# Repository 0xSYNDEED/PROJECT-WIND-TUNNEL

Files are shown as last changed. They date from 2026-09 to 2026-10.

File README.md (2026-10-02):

# Miniature Open-Circuit Subsonic Wind Tunnel

ME 366 (Electromechanical System Design) project, Group A13, Department of Mechanical Engineering, BUET, 2026.

A low-cost wind tunnel with a 160 × 160 × 340 mm test section (16–18 m/s, Re ≈ 1.2 × 10⁵), a dual-lever load-cell balance, surface-pressure taps and a Pitot probe. It was validated against Ansys Fluent simulations of its own test section, with and without the model's support stand. Test models: NACA 4418 airfoil (−5° to +10°) and a 25° Ahmed body.

**Read the report first:** [`[Docs] Wind Tunnel/Wind Tunnel Report - Group A13.pdf`](<[Docs] Wind Tunnel/Wind Tunnel Report - Group A13.pdf>). The poster is in the same folder.

**Authors:** Ahnaf Masud Syndeed, Hasibul Karim Ratul, Mubasshira, Bivashindhu Datta Badhon

## What's where

| Folder | Contents |
|---|---|
| `[Docs] Wind Tunnel/` | Final report (PDF) and poster |
| `[CAD] Wind Tunnel/` | SolidWorks parts and assemblies of the tunnel, balance, models, Pitot stand and smoke rake; DXF files for laser cutting. Parts marked *(Obsolete)* were not used in the final tests |
| `[CFD] Wind Tunnel/` | For every case, with and without the stand: Ansys Discovery geometry prepared for meshing, with named selections (`.dsco`); Fluent project files (`.flprj`); monitor histories (`.out`); simulated geometry (`.STEP`); and Cp exports |
| `[Codes] Wind Tunnel/` | Arduino sketches and MATLAB scripts (below) |

**Arduino** (Mega 2560):

- `LiftDrag_V2` reads the force balance and the Pitot probe.
- `PressureReadings` was used for all reported pressure data.
- `PressureSurvey` is a later, unused rewrite, kept for future surveys.
- `LiftDrag_V1` is the superseded first version of the force sketch.

**MATLAB** (`# MATLAB Scripts/`): all measured data are in `Wind_Tunnel_Experimental_Coefficients.xlsx`. The `[NACA]` and `[Ahmed]` folders hold the scripts that produce the report's comparison plots. `Misc/` holds the averaging script for the oscillating CFD case. Keep the folder structure as it is, because the scripts find their inputs by relative path.

## Software

- **SolidWorks 2026** for the CAD. Use the STEP/DXF files with older versions.
- **Ansys Student 2026 R1**: Discovery for geometry preparation (`.dsco`), and Fluent in Meshing mode (mesh) and Solution mode (solver).
- **MATLAB R2020b or newer.** MATLAB Online works, and no toolboxes are needed.
- **Arduino IDE 2.x** with the `HX711` library by bogde.

## Not included

- **Fluent mesh files** (`.msh.h5`, about 100 MB each), which hold both the mesh and the meshing workflow and open in Fluent's Meshing mode. Most of them exceed GitHub's 100 MB file limit.
- **Fluent case and data files** (`.cas.h5`, `.dat.h5`). With the mesh files, they total about 12 GB.
- **Report source:** only the report PDF is included.
- **3D-print files (STL/3MF):** export them from the SolidWorks parts.
- **Temporary and log files.**

To regenerate the mesh, case and data files, import the `.dsco` geometry in Fluent's Meshing mode and use the settings in the report (Table 2.3).

## License

Code (Arduino firmware and MATLAB scripts) is released under the MIT License (see `LICENSE`). CAD files, data, figures and documents are released under [CC BY 4.0](https://creativecommons.org/licenses/by/4.0/).

## Citation

A. M. Syndeed, H. K. Ratul, Mubasshira, B. D. Badhon, *Design, Instrumentation and CFD Validation of a Miniature Open-Circuit Subsonic Wind Tunnel for Low-Reynolds-Number Aerodynamics*, ME 366 Project Report, BUET, 2026.

Supervised by Dr. Kazi Arafat Rahman, Md Moyeenul Hossain Ratul, Rafiul Haq and Dilshad Jahan Ritu.

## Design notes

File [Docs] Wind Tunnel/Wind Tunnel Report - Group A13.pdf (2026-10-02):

Bangladesh University of

Engineering and Technology

Department of Mechanical Engineering

ME 366 · Electromechanical System Design

Project Report

Design, Instrumentation and CFD Validation

of a Miniature Open⁻Circuit Subsonic Wind Tunnel

for Low⁻Reynolds⁻Number Aerodynamics

Group A13

Submitted by

Ahnaf Masud Syndeed
Student ID 2210047
Hasibul Karim Ratul
Student ID 2210032
Mubasshira
Student ID 2210031
Bivashindhu Datta Badhon
Student ID 2210027

Submitted to

Dr. Kazi Arafat Rahman
Associate Professor
Md Moyeenul Hossain Ratul
Lecturer
Rafiul Haq
Lecturer
Dilshad Jahan Ritu
Lecturer

Date of submission: October 2, 2026

Miniature Subsonic Wind Tunnel: Design & CFD Validation | Group A13 | ME 366

Abstract

Low-cost wind tunnels can give student teams access to low-Reynolds-number aerodynamic testing, but their measurements are only useful once their accuracy is known. This work describes the design, construction and validation of a miniature open-circuit, induced-draft subsonic wind tunnel with a straw honeycomb, a 6.25:1 fifth-order polynomial contraction and a 160 × 160 × 340 mm test section running at 16–18 m/s (Re ≈ 1.2 × 10⁵
). The tunnel is instrumented with a dual-lever load-cell balance for lift and drag, surface-pressure taps read by a differential pressure sensor, a Pitot-static probe and a glycerin-smoke rake, all logged through an Arduino microcontroller. A NACA 4418 airfoil (−5

◦

to 10◦
) and a modified
Ahmed body were tested and compared with steady k–ω SST simulations in Ansys Fluent of the confined test section both with and without the model support stand. The tunnel reproduces the computed trends: the zero-lift angle agrees to within 0.1

◦
(−3.7
- measured), the measured drag lies within 12% of the with-stand simulations, the Ahmed-body drag coefficient is within 9%, and the pressure distributions match the computed shapes. Without the stand in the simulations, the drag differences grow to 22–80%, showing that the support stand adds significant drag that must be modeled in CFD for small-tunnel validation. The measured lift is 15–20% low at 5

◦

and 10◦
, and the measured suction is weaker than predicted; these differences are attributed to low-Reynolds-number boundary-layer effects, balance pivot coupling and calibration, and pressure-line leakage, and improvements are proposed for each.

Keywords: subsonic wind tunnel; low Reynolds number; CFD validation; force balance; surface pressure; NACA 4418; Ahmed body

Contents

Abstract | 1
1 | Introduction | 5
2 | Methodology | 8
3 | Results | 18
4 | Discussion | 23
5 | Conclusion and Future Work | 28
Data and Code Availability | 29
Acknowledgments | 29
A Fabrication and Assembly Sequence | 31
B | Key Code Excerpts | 31
C NACA 4418 Surface Pressure Data | 33

List of Figures

1.1 CAD model of the wind tunnel with the NACA 4418 and the force balance installed,
viewed from the inlet | | 6
2.1 The tunnel as built. Air is drawn from left to right by the fan at the downstream end. . . . | 9
2.2 Side view of the tunnel with principal dimensions (mm), showing the straw honeycomb,
the three screens, the Pitot-static probe and the model position. The flexible coupling and
fan downstream of the diffuser are not shown | 9
2.3 Tunnel details. (a) The settling-chamber inlet with the drinking-straw honeycomb. (b)
CAD side view of the test section with the NACA 4418 on its stand, the stand’s linkage
to the balance below the floor, and the Pitot mount near the inlet (left). (c) CAD view
of the Pitot mount on the test-section floor; the holes in the far wall are the ports for the
pressure-tap tubes | 9
2.4 Test models (CAD renders) and their pressure-tap positions. In (c) the dashed line is the
camber line | 10
2.5 The dual-lever force balance. (a) Drag turns the stand about its lower pivot and is passed, amplified 4.5:1, through the upper link to the drag load cell; lift turns the lower lever about
its pivot and presses, amplified 4:1, on the lift load cell. (b, c) The balance outside the tunnel, with the HX711 amplifiers and the Arduino Mega on the base plate. The servo on
the stand belonged to the original angle-of-attack drive and was not used in the final tests. 12 2.6 Data-acquisition wiring. Both HX711 amplifiers use two digital pins each (data and clock); the pressure sensor feeds analog input A3. The sensor’s reference port stays on
the Pitot static port, and its positive port is switched between the Pitot total port and the
surface taps | 13
2.7 Volume mesh for the NACA 4418 at 0
- with the stand: polyhedral cells with boundary
(prism) layers on the model, the stand and the tunnel walls | 15
2.8 Example of a steady solution that settled into a limit cycle instead of converging (NACA 4418, 10◦
, without stand; period about 98 iterations). The shaded band is the averaging
window of four whole cycles and the dashed lines are the resulting means | 16
3.1 NACA 4418 force coefficients vs. angle of attack: wind tunnel (error bars: estimated
uncertainty) and CFD with and without the model stand | 19
3.2 NACA 4418 lift-to-drag ratio vs. angle of attack | 19
3.3 NACA 4418 surface pressure coefficient at α = −5

◦
, 0

◦
, 5

◦

and 10◦
: wind-tunnel taps
(error bars: estimated uncertainty) vs. the with-stand CFD distribution on the tap plane. . 21 3.4 NACA 4418 tap pressures grouped by surface: wind tunnel (solid) vs. with-stand CFD at
the taps (dashed) for each angle of attack | 21
3.5 Ahmed body upper-surface pressure coefficient along its length: wind tunnel vs. with-stand
CFD (continuous curve and tap means ±1σ of the averaged solution) | 22
3.6 Glycerin smoke-rake visualization of the NACA 4418 (flow from left to right). Images converted to grayscale, sharpened for contrast and cropped to a common frame; no other
processing | 22

List of Tables

1.1 Attributes of a complex engineering problem and how this project meets them | 7
2.1 Test matrix | 13
2.2 Uncertainty inputs | 14
2.3 CFD solver and mesh settings | 15
2.4 Hardware and software components | 16
3.1 Nominal test conditions (ρ = 1.225 kg/m³
) | 18
3.2 NACA 4418 force coefficients: wind tunnel (WT) vs. CFD with and without the model
stand. Δ = (WT − CFD)/|CFD| | 18

3.3 NACA 4418 tap pressure difference C

WT
p − C

CFD
| p

(CFD with stand); WT uncertainty in parentheses. Positive values mean the WT Cp is higher (less suction) than the CFD. Entries within the WT uncertainty are marked ∗
| 20
3.4 Ahmed body drag coefficient. WT ±: estimated uncertainty; CFD ±: 1 SD of the averaged
monitor; Δ = (WT − CFD)/|CFD| | 20
4.1 Drag added by the stand. CFD increment = C

with stand
d

− C

without stand
d

, also given as a
force at the test dynamic pressure and as a share of the with-stand Cd. WT excess

= C

WT
d

− C

without stand
d
| 23
4.2 Challenges faced and how they were resolved | 26
C.1 NACA 4418 tap pressure coefficients: wind tunnel vs. CFD (with stand) | 33

### 1 Introduction

### 1.1 Background and Motivation

Aerodynamic data at Reynolds numbers in the range 10⁴–10⁵ underpin the design of small unmanned aircraft, scale models of ground vehicles and many introductory aerodynamic experiments [1]. In this range the boundary layer stays laminar over much of the surface, and laminar separation, transition and reattachment make the forces sensitive to small changes in Reynolds number, surface finish and freestream turbulence [2]. Such flows are hard to predict, so computations need experimental checks. Wind tunnels that can provide these checks are rarely available to undergraduate teams: commercial teaching tunnels are expensive, and even a recently published open, low-cost design costs several thousand US dollars in hardware [3].
A small tunnel built from commonly available materials can fill this gap, but its measurements are useful only once their accuracy is known, and validating a small facility is difficult. The model blocks a significant fraction of the test section, the support stand is comparable in size to the model and adds drag and interference of its own, and the loads are of the order of one newton or less, close to the resolution of low-cost sensors. This project addresses both needs. It designs, builds and instruments a miniature open-circuit wind tunnel, and then assesses the tunnel’s measurement capability against a computational model of the same confined test section, stand included.

### 1.2 Related Work

Design guidance for small low-speed tunnels is well established. Mehta and Bradshaw [4] give rules for the settling chamber, honeycomb (cell length of six to eight diameters), screens, contraction ratio and diffuser, and Barlow et al. [5] treat tunnel design, instrumentation and wall corrections in detail. For the contraction, Bell and Mehta [6] showed that a fifth-order polynomial wall, with zero slope and curvature at both ends, balances exit-flow uniformity against the risk of boundary-layer separation near the inlet and exit; the profile is widely used in small tunnels and is adopted here. Ismail et al. [3] published an open design for a low-cost, open-loop suction tunnel for aerodynamic testing at up to 15 m/s, with step-by-step build files. The present tunnel uses the same suction layout at a smaller scale, built largely from laser-cut plywood, 3D-printed parts and hobby-grade electronics, and adds a force balance and surface-pressure measurement.
Two standard test models were chosen because their behavior is well documented. The NACA four-digit sections are among the most thoroughly catalogued airfoils [7]; the cambered NACA 4418 produces lift at zero incidence, with a zero-lift angle near −4

◦
, which gives a direct check on the lift measurement. The Ahmed body [8] is the standard simplified road vehicle for bluff-body studies; its wake, and hence its drag, is governed by the rear slant angle, the flow over the slant remaining largely attached below a critical angle of about 30◦
For the computations, steady Reynolds-averaged Navier–Stokes (RANS) simulation with the k–ω SST model [9, 10] is the usual engineering choice. The model treats the boundary layer as fully turbulent from the leading edge, however, so it cannot reproduce the laminar separation and transition that dominate at low Reynolds numbers [2]. This limitation matters for the lift comparison in Section 4.3.

### 1.3 Objectives

The objectives of the project were to:
1. design and build a modular, low-cost, open-circuit subsonic wind tunnel with a 160 mm × 160 mm test section running at 16–18 m/s, giving Re ≈ 1.2 × 10⁵ on a 100 mm chord;
2. instrument the tunnel to measure lift, drag, model surface pressures and freestream speed with a low-cost microcontroller data-acquisition system;
3. build a CFD digital twin of the confined test section, with the support stand included, and use it to assess the tunnel’s force and pressure measurements on a NACA 4418 airfoil (−5

◦

to 10◦
) and a
modified Ahmed body;

4. identify and, where possible, quantify the sources of disagreement, as a basis for improving the facility; and
5. demonstrate qualitative smoke flow visualization.

### 1.4 Facility Overview and Key Features

The tunnel (Fig. 1.1) is an open-circuit, induced-draft facility about 1.6 m long, excluding the fan. Room air enters through a straw honeycomb in a 400 mm × 400 mm settling chamber, is accelerated through a 6.25:1 contraction into the 160 mm × 160 mm, 340 mm long test section, and is slowed in a diffuser before being drawn out by a 350 W axial drum fan. Its main features are:
- Modular, low⁻cost construction: flanged plywood and 3D-printed sections screwed together, so the

tunnel can be taken apart for transport and any section replaced, for a total cost of about BDT 50,000 (under US$500) including scrapped parts (Section 2.8);
- Flow conditioning: drinking-straw honeycomb (L/D ≈ 7), three screens and a fifth-order

polynomial contraction;
- Three measurement modes: a dual-lever load-cell balance for lift and drag, surface-pressure taps

read by a differential pressure sensor, and a Pitot-static probe for the freestream speed;
- Interchangeable models: 3D-printed NACA 4418 and Ahmed-body models with built-in pressure

taps, mounted on a stand linked to the balance;
- Optical access and flow visualization: an acrylic side window and a removable glycerin-smoke

rake;
- Open tools: Arduino firmware and MATLAB scripts, with code and CAD shared in a public

repository (see Data and Code Availability); and
- CFD digital twin: an Ansys Fluent model of the confined test section, model and stand, used to

validate the measurements.
The design, instrumentation and procedures are described in Section 2, the results in Section 3 and their interpretation in Section 4.

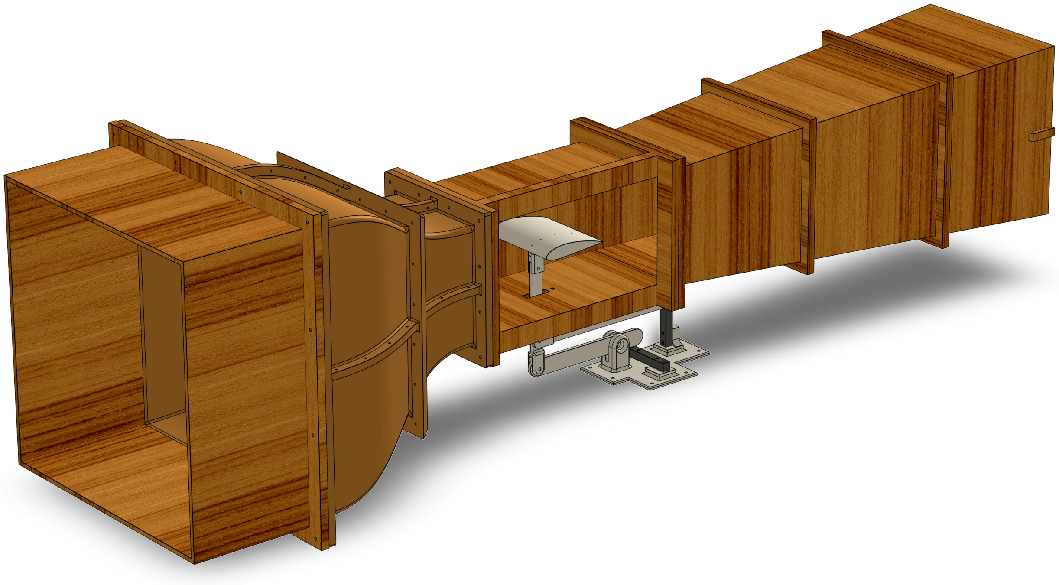
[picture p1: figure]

Figure 1.1: CAD model of the wind tunnel with the NACA 4418 and the force balance installed, viewed from the inlet.

### 1.5 The Project as a Complex Engineering Problem

Under the graduate-attribute framework of the International Engineering Alliance [11], adopted by the Board of Accreditation for Engineering and Technical Education (BAETE), a complex engineering problem (CEP) is one that cannot be resolved without in-depth engineering knowledge (attribute P1) and that also has some or all of attributes P2–P7. This project has attributes P1–P4 and P7 in full and P5 and P6 in part, as summarized in Table 1.1 together with the sections of this report that support each one. Resolving it also involved complex engineering activities: it drew on diverse resources, from laser cutting, 3D printing and electronics to commercial CFD software (A1); it required resolving interactions between conflicting technical issues, such as the stand’s interference with the drag measurement (A2); it used engineering principles in new ways, including a drinking-straw honeycomb, printed internal tap channels and a balance whose model stand is itself the drag lever (A3); and it went beyond the team’s previous experience through a principles-based approach (A5).

Table 1.1: Attributes of a complex engineering problem [11] and how this project meets them.

Attribute | How the project meets it | Evidence

P1
Depth of
knowledge

Requires engineering fundamentals (K3: fluid mechanics of contractions, diffusers, Pitot measurement and boundary layers; lever statics and load-cell calibration), specialist knowledge (K4: low-Reynolds-number aerodynamics, RANS turbulence modeling and near-wall meshing), design knowledge (K5: honeycomb, screen, contraction and diffuser sizing), knowledge of practice (K6: laser cutting, 3D printing, sensors and microcontroller data acquisition) and the research literature (K8).

Sections A, 1.2
and 2

P2
Conflicting
requirements

Flow quality against size and cost (contraction ratio and length, number of screens); Reynolds number against blockage in a
160 mm × 160 mm section; balance sensitivity (lever gain) against stiffness; a stand rigid enough to hold the model but small enough to add little drag; one pressure sensor shared between the Pitot probe and the taps; and a fan with enough pressure rise to overcome the conditioning losses at low cost.

Sections 2.1, 2.3
and 4.6

P3
Depth of analysis

No standard solution exists. The contraction wall profile, the dual-lever force resolution and calibration, the CFD model of the confined test section with the stand, the averaging of oscillating solutions and the uncertainty analysis all had to be formulated for this facility, and separating the stand’s drag from the model’s needed a dedicated with/without-stand comparison.

Sections 2.5, 2.6
and 4.2

P4
Infrequent issues

Laminar separation and transition at Re ≈ 10⁵
, loads of the order of
one newton, near the resolution of low-cost sensors, a support stand comparable in size to the model, steady RANS solutions that settle into limit cycles, and leakage in long pressure lines.

Sections 4.3 to 4.5

P5
Beyond codes
(partial)

The components were sized with published empirical guidance [4–6], but no code covers the validation of a miniature tunnel, so the validation against a CFD model of the same test section, stand included, was developed within the project.

Sections 2.1
and 2.6

P6
Diverse
stakeholders
(partial)

Future student users need a safe, simple and trustworthy facility; the course sets the schedule and learning outcomes; and the budget and local market limited the materials and the fan. No external user was consulted.

Section 2.4;
Data and Code
Availability

P7
Interdependence

The tunnel, force balance, pressure system, data acquisition, test models and CFD model are interdependent sub-problems: the fan choice sets the test speed and Reynolds number, the stand design affects both the balance and the measured drag, the screen position constrains the Pitot probe, and the CFD model must reproduce the stand, the walls and the test conditions for the comparison to be valid.

Sections 2 and 4.1

### 2 Methodology

### 2.1 Tunnel Design and Fabrication

The tunnel is an open-circuit, induced-draft (suction) design: a fan at the downstream end draws room air through the tunnel, so the flow reaches the test section before it has passed through the fan. The flow path, shown in Fig. 2.1, consists of the settling chamber with its honeycomb, the contraction, the test section, the diffuser, the flexible coupling and the fan. The plywood panels (6 mm) and the acrylic window (6 mm) were laser-cut from 2D layouts drawn as SolidWorks sketches and exported as DXF files, with all plywood panels nested on a single 4 × 8 ft sheet; the 3D CAD model served only as the dimensional reference. The panels were bonded with cyanoacrylate adhesive. The contraction, models, balance levers and smoke rake were 3D-printed in PLA on a Bambu Lab A1 printer. The seams of the plywood panels were strengthened with epoxy fillets, and the sections were joined to each other with M3 and M4 screws. The fabrication and assembly sequence is summarized in Section A.

Settling chamber and flow conditioning. The settling chamber has a 400 mm × 400 mm cross-section. It holds a honeycomb made of drinking straws (bubble-tea straws, cell diameter about 10 mm) cut to 70 mm with a hot wire, giving L/D ≈ 7, within the recommended range of 6–8 [4]; about 2000 straw sections (just over 1000 straws, each cut in half) fill the cross-section. Three wire-mesh screens with a 2 mm mesh are fitted: one at the downstream end of the settling chamber, one at the contraction exit and one downstream of the test section, ahead of the diffuser.

Contraction. The contraction reduces the 400 mm × 400 mm inlet to the 160 mm × 160 mm test section, an area ratio of 6.25:1. Its wall follows the fifth-order polynomial recommended by Bell and Mehta [6], which has zero slope and zero curvature at both ends:

y(x) = ℎi − (ℎi − ℎe)

10
x

L

3
− 15
x

L

4
+ 6
x

L

5

, | (1)
where y is the wall half-height, ℎi = 200 mm and ℎe | = 80 mm are the inlet and exit half-heights, and
L = 370 mm is the contraction length (L/2ℎi ≈ 0.93). A doubly curved wall of this size cannot be formed from sheet plywood and is too large for a desktop printer, so the contraction was printed in eight flanged segments, screwed together, and the gaps between the segments were sealed by pouring in epoxy; the inner surface was then coated with epoxy to smooth the rough finish of the large prints.

Test section. The test section measures 160 × 160 × 340 mm. It is built from 6 mm plywood, with a removable 6 mm acrylic window for optical access that is screwed to flanges along the top and bottom of the open side. The floor has three openings: a rectangular slot for the model stand, a 20 mm hole for the Pitot holder and a second 20 mm hole the same distance on the other side of the mid-plane, used for lighting in the visualization runs and taped over otherwise. The model is mounted on a stand passing through the floor to the force balance underneath (Section 2.3). The freestream speed is measured by an ArduPilot-type (APM) airspeed Pitot-static probe [12]. Its 3D-printed mount stands 35 mm downstream of the test-section inlet and 15 mm off the mid-plane toward the window, and holds the probe 44 mm above the floor (Fig. 2.3); its base plug closes the floor hole and has two holes through which the probe’s tubes leave the test section. The probe points upstream through a hole in the contraction-exit screen, so its tip lies just inside the contraction, clear of the screen wakes, and it is out of the plane of the stand with no part of the model or stand directly downstream of it.

Diffuser and drive. A linear diffuser, 695 mm long, expands the section from 160 mm × 160 mm to 250 mm × 250 mm (area ratio 2.44, wall half-angle 3.7

◦
) and slows the flow before the fan. The diffuser exit is joined to the fan by a flexible coupling, a tarpaulin sleeve tightened with metal cable ties and rope, which keeps fan vibration from reaching the tunnel. The drive is a 14 in, 350 W, 2800 rpm axial drum fan rated at over 2000 CFM, controlled by an AC 220 V, 2000 W SCR voltage regulator. With a model installed it gives 16–18 m/s (57–65 km/h) in the test section; the empty test section reaches about 19 m/s.

Settling chamber
+ honeycomb

Contraction
(6.25:1)
Test section | Diffuser

Flexible
coupling | Fan

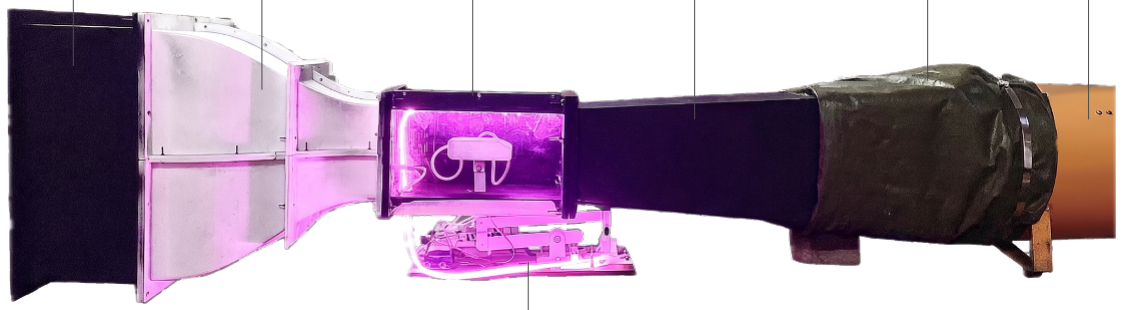
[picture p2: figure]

Force balance Flow

Figure 2.1: The tunnel as built. Air is drawn from left to right by the fan at the downstream end.

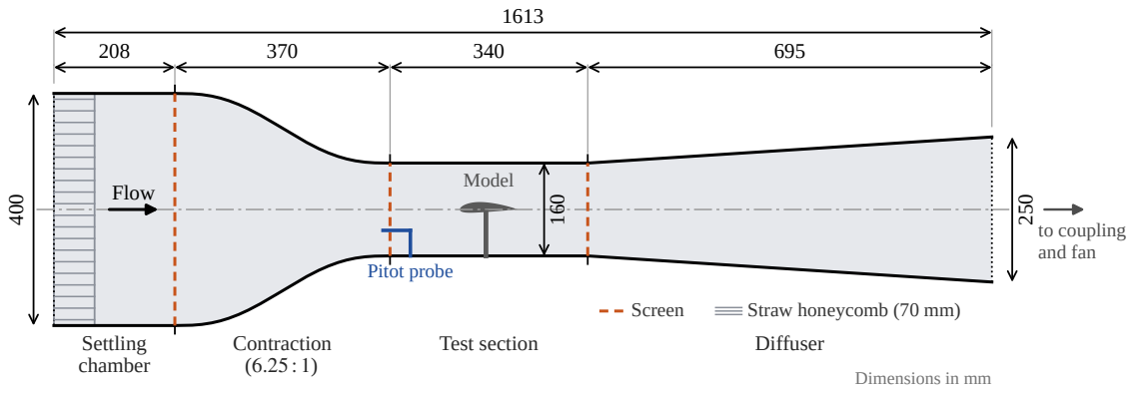
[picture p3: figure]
Settling chamber; Contraction (6.25 : 1); Test section; Diffuser; Pitot probe; Model Flow; to coupling and fan; Screen; Straw honeycomb (70 mm); Dimensions in mm

Figure 2.2: Side view of the tunnel with principal dimensions (mm), showing the straw honeycomb, the three screens, the Pitot-static probe and the model position. The flexible coupling and fan downstream of the diffuser are not shown.

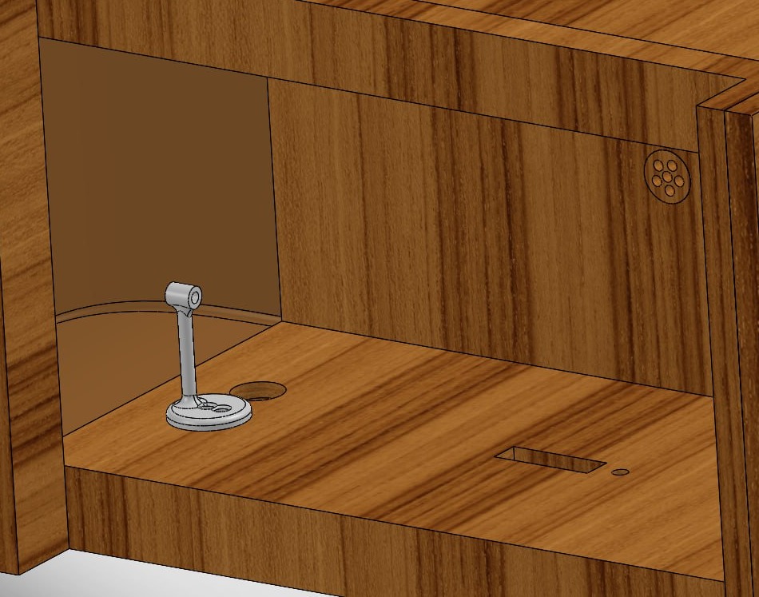
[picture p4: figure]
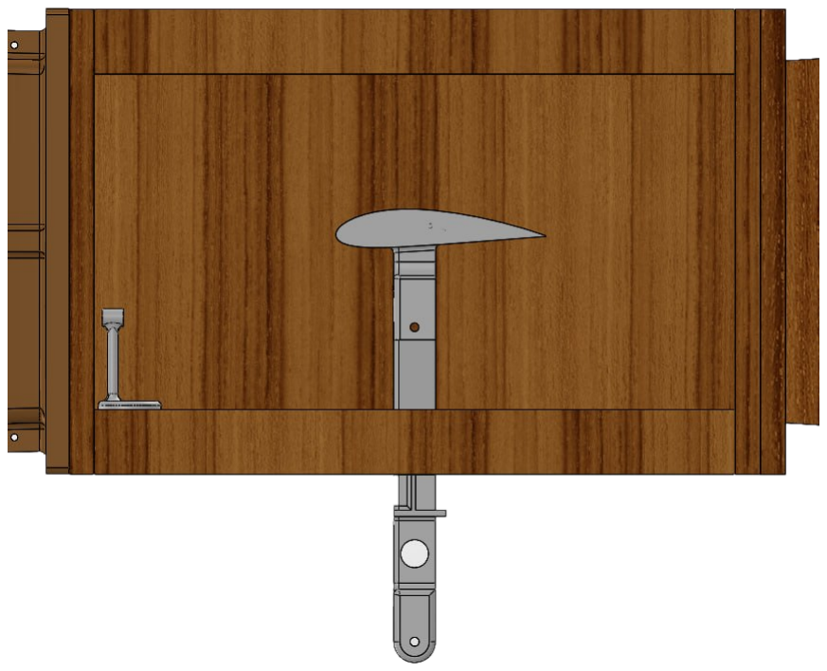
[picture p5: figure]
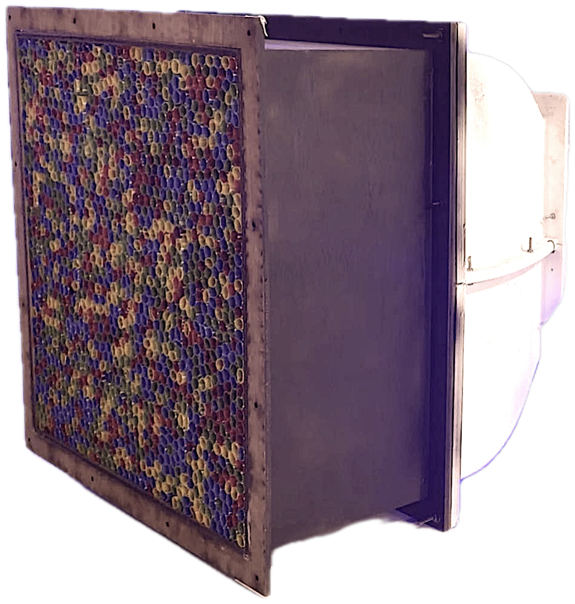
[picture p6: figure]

(a) Straw honeycomb | (b) Test section, side view | (c) Pitot mount

Figure 2.3: Tunnel details. (a) The settling-chamber inlet with the drinking-straw honeycomb. (b) CAD side view of the test section with the NACA 4418 on its stand, the stand’s linkage to the balance below the floor, and the Pitot mount near the inlet (left). (c) CAD view of the Pitot mount on the test-section floor; the holes in the far wall are the ports for the pressure-tap tubes.

### 2.2 Test Models and Support Stand

Both models were 3D-printed in PLA with four wall loops, to keep the printed tap channels airtight (Fig. 2.4). Pressure taps are 1 mm holes normal to the surface.

NACA 4418 airfoil. The airfoil has a chord of c = 100 mm and a span of 125 mm, leaving gaps of 10 mm and 25 mm to the window and the opposite wall. The reference area for the force coefficients is the planform area, Aref = 0.0125 m²
. Four taps on the upper surface (x/c = 0.05, 0.20, 0.45, 0.75) and four on the lower surface (x/c = 0.12, 0.27, 0.52, 0.68) lie in one chordwise plane, 25 mm from the test-section mid-plane toward the window (Fig. 2.4c); each is connected to an external nozzle by a channel printed inside the model. The lower tap at x/c = 0.68 gave unreliable readings and is excluded, leaving seven taps.

Ahmed body. The bluff-body model is a modified Ahmed body [8], 120 mm long, 40 mm wide and 37 mm high, with a front radius of 11.5 mm. Its rear slant is 28.2 mm long and drops to a 25 mm high base, giving a slant angle of 25◦
. The body is taller relative to its width than the original, which lets more smoke streaks pass over its upper surface in the visualization runs while keeping a similar frontal area. The reference area is the frontal area, Aref = 1.48 × 10⁻³ m²
. Eight taps run along the upper surface, on the mid-plane, at x/L = 0.05, 0.13, 0.32, 0.55, 0.72, 0.82, 0.90 and 0.96, the last three on the slant (Fig. 2.4d). To avoid the leakage-prone printed internal channels, the Ahmed body was built with its tubes entering from the side and connecting directly behind each tap.

Support stand. Each model sits on a vertical stand whose streamlined sting is 20 mm long in the flow direction, with a 5 mm round leading edge tapering to a 2 mm trailing edge. The sting joins a mount with a 10 mm × 5 mm through-hole. The NACA model rotates about a pivot about 38 mm below its chord line, so changing the angle of attack also moves it slightly forward or aft. The angle is set by hand with a protractor.

Blockage. At 0

◦
the airfoil’s frontal area (125 × 18 mm) is 8.8% of the test-section cross-section, or about 10% including the stand, and it grows with angle of attack. The Ahmed body’s frontal area is 5.8% of the cross-section. No blockage correction is applied; the CFD reproduces the same confinement (Section 2.6).

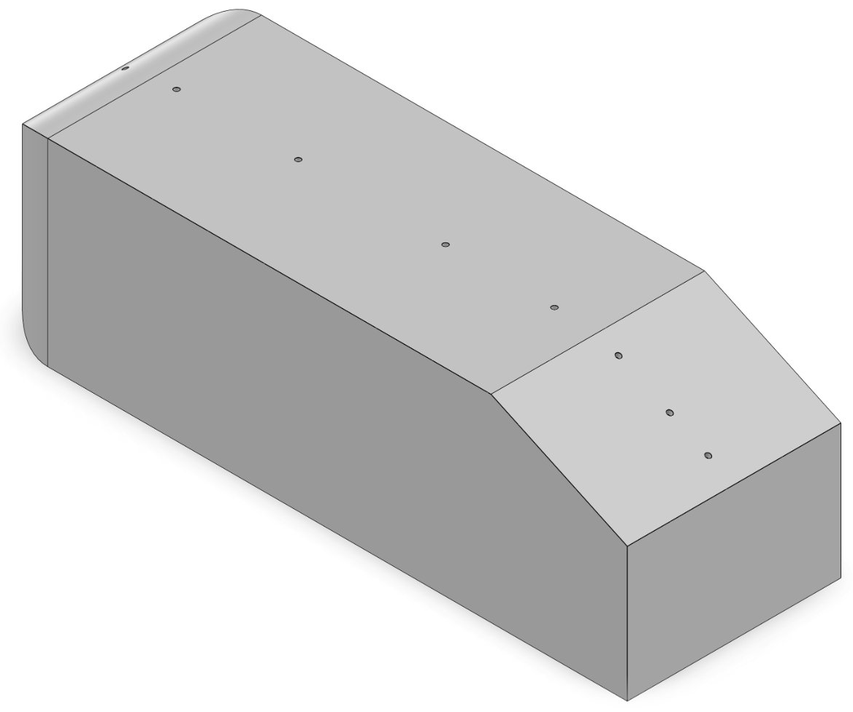
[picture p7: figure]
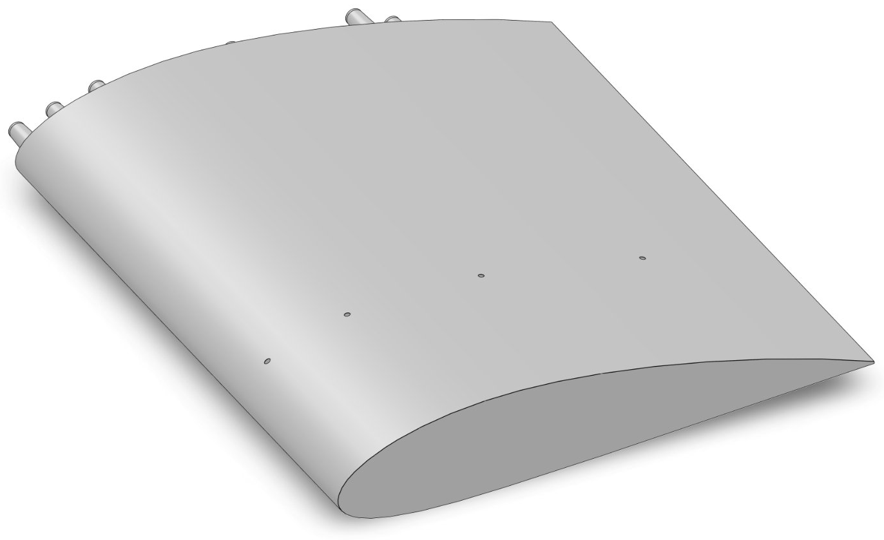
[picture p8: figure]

(a) NACA 4418 | (b) Ahmed body

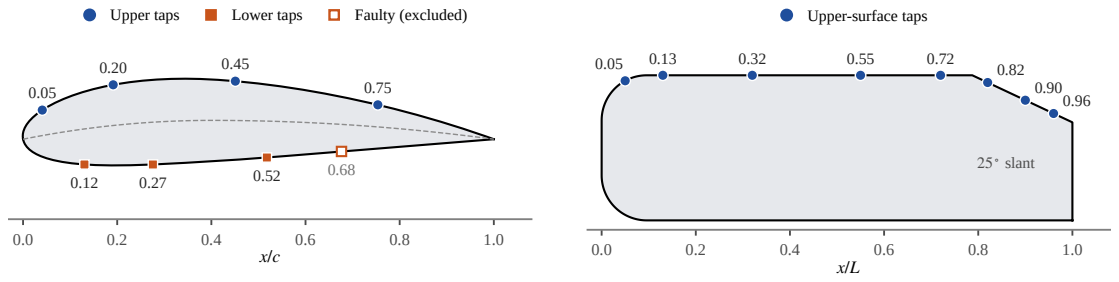
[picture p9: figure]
Upper taps; Lower taps; Faulty (excluded); slant; Upper-surface taps

(c) NACA 4418 tap locations
(d) Ahmed body tap locations (side view)

Figure 2.4: Test models (CAD renders) and their pressure-tap positions. In (c) the dashed line is the camber line.

### 2.3 Instrumentation and Data Acquisition

All sensors are read by an Arduino Mega 2560 [13] and streamed over USB serial to a PC, where the logged data are reduced and plotted in MATLAB Online; key excerpts of the firmware and scripts are given in Section B. The wiring is shown in Fig. 2.6.

Freestream speed. A single MPXV7002DP differential pressure sensor [14] serves both pressure measurements, because the tunnel has one Pitot-static tube, used either to measure the speed or as the static reference for the taps. For speed measurement the Pitot-static tube is connected across the sensor (±2 kPa, 1 V/kPa at a 5 V supply), read by the Arduino’s 10-bit ADC. The sensor output is ratiometric, so its sensitivity is scaled to the measured supply rail (4.93 V). Before every run the zero-pressure output is recorded with the fan off as the mean of 100 samples and subtracted from all later readings. The speed follows from the Pitot pressure difference,

U∞ =

√︄
2 ΔpPitot

ρair

, | (2)

with the density of the tunnel air, ρair = 1.164 kg/m³

at about 30 ◦C.

Force balance. Lift and drag are measured by a dual-lever balance below the test section (Fig. 2.5). The stand itself is the drag lever: it pivots at its lower end, and a horizontal link attached partway up carries the drag, amplified 4.5:1, to the drag load cell. The stand’s pivot sits on one end of the lift lever, which turns about a fixed pivot and presses on the lift load cell with its other end, amplifying the lift 4:1. Every pivot and joint runs on 624ZZ ball bearings: two at the lift-lever pivot and one each at the drag-lever pivot and at the joint between the stand and the drag link. The levers and the link are printed in PLA, and both load cells are 1 kg straight-bar cells, each read by an HX711 24-bit bridge amplifier [15] at 10 samples per second. Each channel was calibrated with the lever system assembled but without the model, so the lever ratio is contained in the calibration slope. The calibration used two points, zero load and one known mass (weighed on a kitchen scale), with the slope stored in the Arduino’s EEPROM (Listing B.1). Objects of other known masses were then read correctly to within the ±3 g (0.03 N) band adopted as the force uncertainty (Section 2.5), and a 31 g reference still read 31 g several weeks later. The balance is re-tared, fan off, at the start of every test. During a run, each output line averages five conversions from each load cell together with the Pitot signal sampled at 1 kHz over the same window (about 500 samples), giving about two readings per second.

Surface pressure. Each tap is connected by a silicone tube (2.5 mm bore, 5 mm outside diameter, about 0.75 m long) to the positive port of the MPXV7002DP, while the reference port stays connected to the Pitot static port. The sensor therefore reads the tap pressure relative to freestream static pressure directly. The taps are connected one at a time by hand; the firmware streams the tap pressure, each value the mean of 20 samples, and the reading is recorded once it has settled. Because the single sensor is occupied by the tap, the dynamic pressure cannot be measured while the taps are read (Section 2.4).

### 2.4 Test Procedure and Data Reduction

Each test began with the model mounted and set to the required angle of attack, with the load cells calibrated as described in Section 2.3. The tunnel was then operated in one of three modes; Table 2.1 lists the tests.

Force tests. The tap tubes remained detached during the force tests. One set of eight tubes serves the taps of either model and is attached only for the surface-pressure tests: any contact with the model or the balance levers biases the force readings, and the tubes, which leave the tunnel through small holes in the wall, would keep the model from moving freely. Both Pitot ports were connected across the pressure sensor. The Arduino program for force and speed measurement was started with the fan off, so that the load cells and the pressure sensor were tared at zero flow; the fan was then brought up to speed and allowed to settle before lift, drag and freestream speed were recorded. The balance was re-tared before each angle of attack and each model.

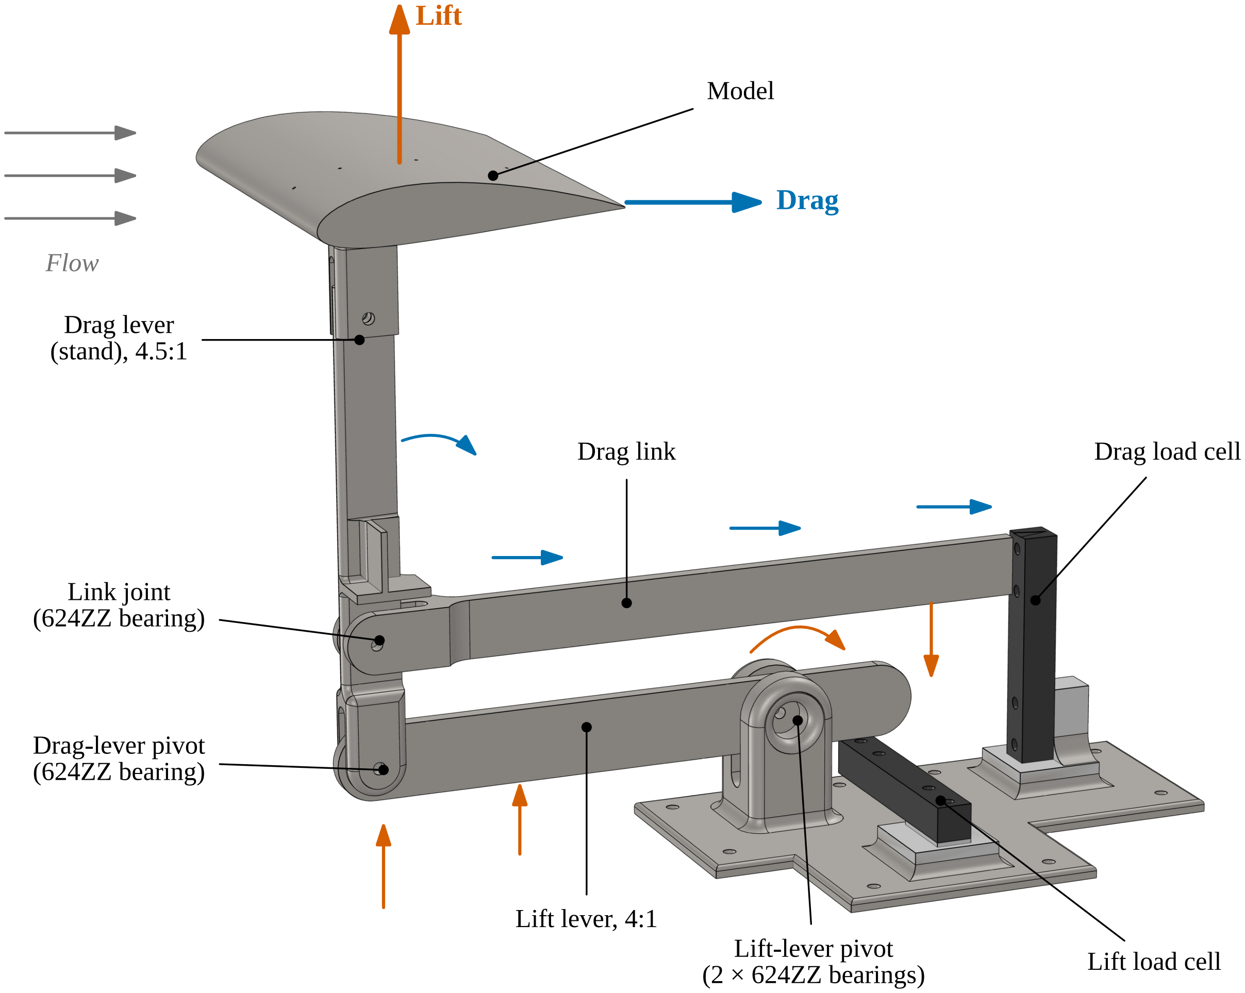
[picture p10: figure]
Flow; Drag; Model; Drag lever (stand), 4.5:1; Link joint (624ZZ bearing); Drag-lever pivot (624ZZ bearing); Drag link; Drag load cell; Lift lever, 4:1; Lift-lever pivot; (2 × 624ZZ bearings); Lift load cell

(a) CAD model with the load paths

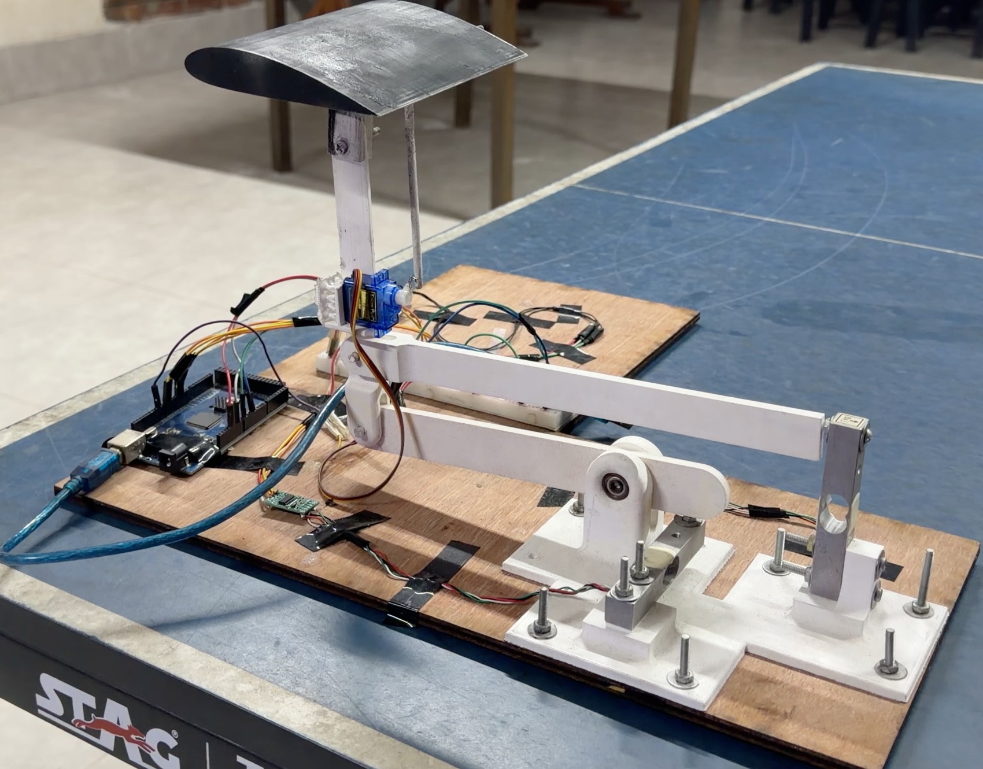
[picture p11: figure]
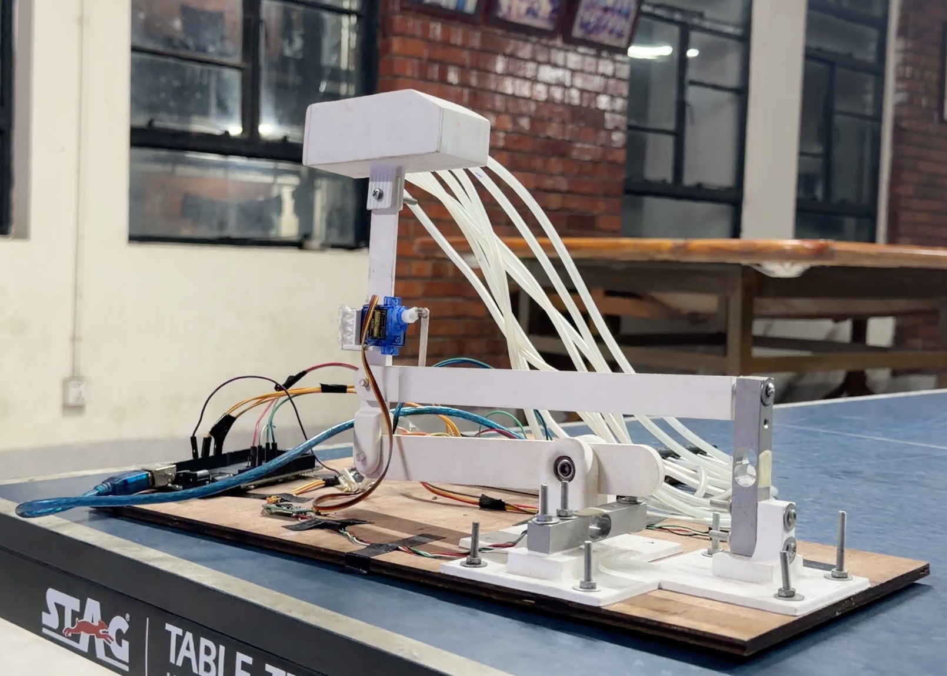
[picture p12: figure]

(b) Built, with the NACA 4418 | (c) Built, with the Ahmed body and its tubes

Figure 2.5: The dual-lever force balance. (a) Drag turns the stand about its lower pivot and is passed, amplified 4.5:1, through the upper link to the drag load cell; lift turns the lower lever about its pivot and presses, amplified 4:1, on the lift load cell. (b, c) The balance outside the tunnel, with the HX711 amplifiers and the Arduino Mega on the base plate. The servo on the stand belonged to the original angle-of-attack drive and was not used in the final tests.

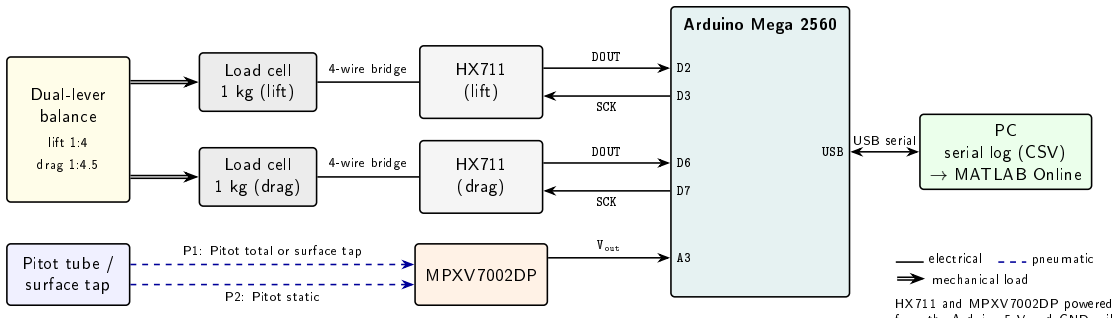
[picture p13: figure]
Arduino Mega 2560; USB; HX711 (lift); HX711 (drag); MPXV7002DP; DOUT; SCK; Vout; Load cell 1 kg (lift); Load cell 1 kg (drag); 4-wire bridge; Dual-lever balance; lift 1:4; drag 1:4.5; Pitot tube / surface tap; P1: Pitot total or surface tap; P2: Pitot static; PC serial log (CSV) → MATLAB Online; USB serial; electrical; pneumatic; mechanical load; HX711 and MPXV7002DP powered

from the Arduino 5 V and GND rails

Figure 2.6: Data-acquisition wiring. Both HX711 amplifiers use two digital pins each (data and clock); the pressure sensor feeds analog input A3. The sensor’s reference port stays on the Pitot static port, and its positive port is switched between the Pitot total port and the surface taps.

Surface-pressure tests. For the surface-pressure tests the eight tap tubes were attached to the model’s nozzles and routed out of the tunnel through the holes in the wall opposite the window. The Arduino program for pressure measurement was started with the fan off and both Pitot ports connected across the sensor, so that the sensor zero was recorded at zero flow; a reference Pitot reading was taken once the fan was running. The Pitot total-pressure line was then removed from the sensor’s positive port and replaced by each tap tube in turn, the static line remaining on the reference port, so that each tap pressure was measured relative to the freestream static pressure. Because the sensor was occupied by a tap, the dynamic pressure could not be measured at the same time, and the nominal test speed was used to compute Cp.

Flow visualization. The Pitot holder was removed and the smoke rake fitted in its floor hole (Section 2.7). The tunnel was run at about 5 m/s, because at higher speeds the smoke streaks became turbulent and diffused before reaching the model.

Table 2.1: Test matrix.

Model | Quantity | α | U∞ (m/s)
NACA 4418 | Cl
, Cd | −5

◦
, 0
| | ◦ , 5

◦

, 10◦ | 17.5
NACA 4418 | Cp (7 taps) | −5

◦
, 0
| | ◦ , 5

◦

, 10◦ | 17.5
Ahmed body | Cd | – | 16
Ahmed body | Cp (8 taps) | – | 16
NACA 4418 | Smoke visualization | −5
| | ◦ , 0 | ◦ ≈ 5

The forces, in grams, are converted to newtons and reduced to coefficients with the freestream dynamic pressure

q∞ =

1
2

ρref U

2

∞, | Cl = L
| q∞ Aref
, | Cd =
| | D
| | q∞ Aref
, | Cp =
| | | p − p∞

q∞

, | (3)

where p − p∞ is the tap reading relative to the Pitot static port. All coefficients, from the tunnel and the CFD alike, use the reference density ρref = 1.225 kg/m³
; the speeds in Eq. (2) use the actual air density. Because the tunnel air is less dense than ρref, this makes q∞ about 5% larger than the true dynamic pressure at the measured speed; the effect is discussed in Section 4.5. The nominal speeds give q∞ = 187.6 Pa for the NACA 4418 and 156.8 Pa for the Ahmed body. The Reynolds number based on the NACA chord is about 1.2 × 10⁵

, and on the Ahmed body length about 1.3 × 10⁵ (Table 3.1).

### 2.5 Uncertainty Analysis

The uncertainties are estimates based on resolution and observed reading fluctuation. They do not include sensor non-linearity or drift, tap position errors, angle-setting error, balance cross-coupling or the stand’s drag; these systematic effects are discussed in Section 4.5. Table 2.2 lists the inputs. They are propagated by root-sum-square (Listing B.5), using δq∞/q∞ = 2 δU/U∞:

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
2 δU

U∞

2
, | δCp =

√︄
δ p

q∞

2
+
Cp

2 δU

U∞

2
, | (4)

where CF stands for Cl or Cd and F for the corresponding force. For the lift-to-drag ratio the dynamic pressure cancels, so δ(L/D)/(L/D) =

√︁
(δL/L)

2 + (δD/D)

2

Table 2.2: Uncertainty inputs.

Quantity | Uncertainty | Basis
Force, δF | ±0.03 N (±3 g) | Observed reading fluctuation; calibration check
Pressure, δ p | ±4.9 Pa | One ADC count (4.9 mV) at 1 V/kPa
Speed, force runs | ±0.5 m/s | About twice the Pitot resolution (0.23 m/s at 17.5 m/s)
Speed, pressure runs | ±1.25 m/s | Fluctuation of about ±1.25 m/s about the nominal speed; q∞ not measured during tap readings

The resulting uncertainties are ±0.013 to ±0.037 in Cl

, ±0.013 to ±0.015 in the NACA 4418 Cd, ±0.134 in the Ahmed body Cd, and ±0.027 to ±0.136 in Cp. The speed term dominates for the pressure data (±14% in q∞ at 17.5 m/s and ±16% at 16 m/s), while the force term dominates for small forces such as the drag.

### 2.6 Computational Setup (CFD Digital Twin)

The CFD reproduces the tunnel test rather than free flight. The domain is the 160 mm × 160 mm test section at its real 340 mm length, with the model and its stand in their tunnel positions and no-slip walls on all tunnel surfaces, so blockage and wall effects are the same as in the experiment. The upstream screens and contraction are not modeled; the inlet delivers a uniform flow. Each case was run twice, with and without the stand. The stand-free runs represent the model alone; the with-stand runs are a digital twin of the actual setup and test the measurement system as a whole. The solver and mesh settings are listed in Table 2.3.
The geometry was prepared for meshing in Ansys Discovery (Ansys Student 2026 R1), where named selections were also defined for the boundaries and force-report zones. The CAD was simplified: the taps, their internal channels and the tube connectors were removed, together with the stand’s edge fillets, and enclosed dead-air cavities were filled. The sting profile and the 10 mm × 5 mm through-hole in the mount, through which air flows, were kept exactly. The volume mesh was generated in Fluent’s Meshing mode, with boundary layers (prism cells) on the model, stand and tunnel walls created in the workflow’s Add Boundary Layers step. Their first-layer height was set from a flat-plate estimate for a target of y

+ ≈ 1;
because y

+ depends on the computed wall shear, it could only be checked after the solution, which gave

y

+ ≈ 1.7 overall and 1.9 on the stand. The mesh also uses offset-surface refinement around the model and stand and local sizing at thin trailing edges and junctions. The student license’s cell limit restricted refinement. The 10◦ with-stand case used additional wake refinement. No mesh-independence study was carried out.
Several solutions, especially those with the stand, did not converge in the residuals because the flow is mildly unsteady. Each run was continued until the Cl

, Cd and tap-Cp monitors were constant to three significant figures. Two cases kept oscillating. The stand-free 10◦
case settled into a regular limit cycle (Fig. 2.8); its cycles were located from the drag-coefficient peaks and the monitors were averaged over the last four whole cycles, accepting the mean only when it changed by less than 0.5% between the last two and the last four cycles (Listing B.3). In the with-stand Ahmed-body case the slant pressures oscillated irregularly, so its monitors were averaged over a fixed window after the start-up transient, and the window was checked by comparing the means of its two halves (Listing B.4). In both cases the standard deviation is reported as the CFD spread, and the mean is compared with the experiment because the balance and pressure sensors also time-average. These and all other data-reduction and plotting scripts are available in the project repository (see Data and Code Availability). Force reports were checked zone by zone to include only model and stand surfaces. Tap Cp values were read from the pressure distribution along the tap plane: the exported curve was rotated into the chord frame, split into upper and lower surfaces, and interpolated at the tap positions (Listing B.2).

Table 2.3: CFD solver and mesh settings.

Setting | Value
Software | Ansys Student 2026 R1: Discovery (geometry preparation) and Fluent
| (Meshing mode for the mesh, Solution mode for the solver)
Solver | Pressure-based, steady; Fluent default schemes; energy equation on
Turbulence model | k–ω SST [9, 10]
Domain | Test section, 160 mm × 160 mm × 340 mm, model and stand at tunnel
| positions
Inlet | Velocity inlet, 17.5 m/s (NACA 4418) or 16 m/s (Ahmed body);
| default turbulence settings
Outlet | Pressure outlet, default settings (0 Pa gauge)
Walls | No-slip: tunnel walls, model, stand
Fluid | Air, ρ = 1.225 kg/m³
Reference values | ρ = 1.225 kg/m³ ; U as inlet; Aref as in Section 2.2
Boundary layers | 15–18 layers, growth rate 1.1; y + ≈ 1.7
Volume mesh | Polyhedra (all NACA 4418 cases), poly-hexcore (Ahmed body); growth
| rate 1.2; minimum orthogonal quality 0.15–0.2 after the Improve
| Volume Mesh task
Convergence | Monitors constant to 3 s.f., or averaged over whole oscillation cycles

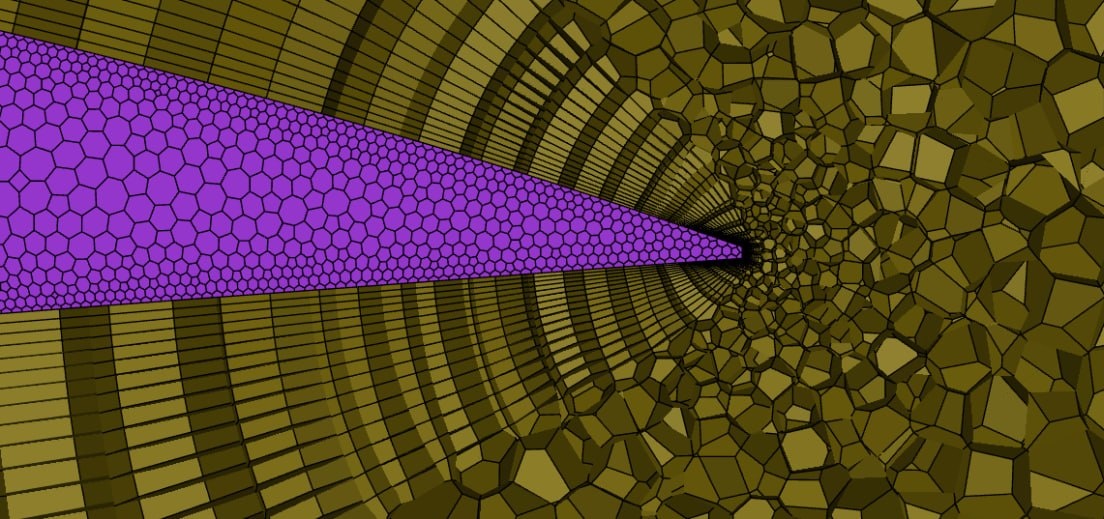
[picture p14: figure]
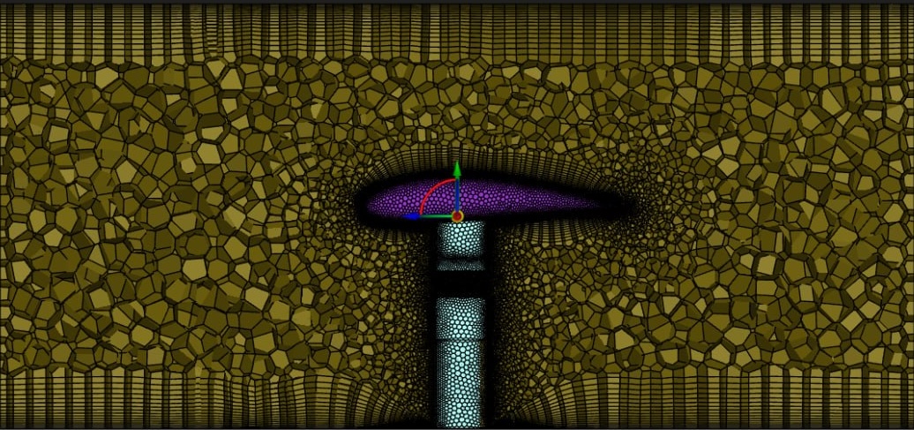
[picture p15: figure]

(a) Mid-plane cut: test section, model and stand | (b) Close-up of the trailing edge

Figure 2.7: Volume mesh for the NACA 4418 at 0

- with the stand: polyhedral cells with boundary (prism) layers on the model, the stand and the tunnel walls.

### 2.7 Flow Visualization

Smoke is produced by heating glycerin-soaked cotton with a soldering iron inside a smoke chamber, which is connected directly to a removable rake of six 3D-printed PLA nozzles (4 mm outlet diameter). For these runs the rake replaces the Pitot holder in its floor hole, upstream of the model and offset sideways to clear the stand, and releases streaks that pass over the model; an LED strip inserted through the second floor hole lights the streaks. The visualization is qualitative and was not used for any quantitative result.

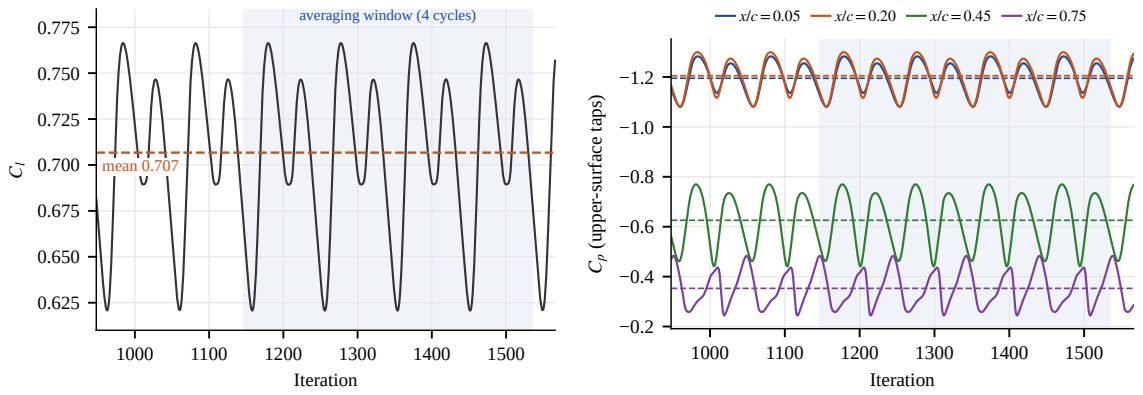
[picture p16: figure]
Iteration; mean 0.707; averaging window (4 cycles); Cp (upper-surface taps)

(a) Lift coefficient
(b) Upper-surface tap pressure coefficients

Figure 2.8: Example of a steady solution that settled into a limit cycle instead of converging (NACA 4418, 10◦
, without stand;
period about 98 iterations). The shaded band is the averaging window of four whole cycles and the dashed lines are the resulting means.

### 2.8 Hardware and Software Components

Table 2.4 lists the main hardware and software components, their ratings and their functions. The complete facility, including the instruments and test models, cost about BDT 50,000 (under US$500). This total includes parts that were scrapped along the way. The contraction, expected to need about BDT 4,000 of filament, took about BDT 6,500 because of failed prints; the four server fans, bought for BDT 2,400, were dropped when they could not reach the target speed (Table 4.2); and several prints were never used, among them the abandoned tap selector and two Ahmed bodies that broke or were misprinted.

Table 2.4: Hardware and software components.

Category | Component | Rating / spec | Function
Structure | Plywood panels | 6 mm, laser-cut | Settling chamber, test section, diffuser, frame
Structure | Acrylic window | 6 mm | Optical access to the test section
Structure | 3D-printed parts | PLA, Bambu Lab A1 | Contraction (8 segments), models, levers, Pitot mount, smoke rake
Structure | Fasteners | M3 and M4 screws | Join tunnel sections and balance parts
Structure | Flexible coupling | Tarpaulin sleeve, metal cable ties, rope | Joins diffuser to fan; isolates vibration
Structure | Adhesive and sealant | Cyanoacrylate; epoxy resin | Bond plywood panels; strengthen plywood seams (fillets); seal and smooth the contraction
Flow | Straw honeycomb | About 2000 straw sections (1000+ straws cut in half); 70 mm long, ∼10 mm cells, L/D ≈ 7 | Removes swirl and large eddies
Flow | Screens ×3 | Wire mesh, 2 mm | Turbulence reduction (two upstream of the model); one ahead of the diffuser
Flow | Contraction | 6.25:1, fifth-order profile | Accelerates and evens the flow
Drive | Axial drum fan | 14 in, 350 W, 2800 rpm, 2000+ CFM | Draws air through the tunnel
| | | continued

Category | Component | Rating / spec | Function
Drive | SCR voltage regulator | AC 220 V, 2000 W | Sets the fan speed (open loop)
Force | Dual-lever balance | PLA levers; 4:1 lift, 4.5:1 drag | Amplifies the small aerodynamic loads
Force | Ball bearings ×4 | 624ZZ (4 × 13 × 5 mm, shielded) | Lever pivots and link joint (2 at the lift-lever pivot)
Force | Load cells ×2 | 1 kg, straight bar | Lift and drag measurement
Force | HX711 ×2 | 24-bit bridge ADC, 10 samples/s | Load-cell signal conditioning
Pressure | MPXV7002DP | ±2 kPa, 1 V/kPa | Pitot pressure and tap pressures
Pressure | Pitot-static probe | APM (ArduPilot) airspeed probe [12], printed mount | Freestream speed; static reference for taps
Pressure | Silicone tubing | 2.5 mm bore, 5 mm OD, about 6 m in 8 lengths | Connects taps to the sensor
DAQ | Arduino Mega 2560 | ATmega2560, 5 V, 10-bit ADC | Sampling, taring, serial output
Flow vis. | Smoke rake | 6 nozzles, 4 mm outlet; glycerin smoke | Qualitative flow visualization
Software | Arduino firmware | C++, Arduino IDE | Data acquisition and taring (see repository)
Software | MATLAB Online | – | Data reduction and plotting (see repository)
Software | Ansys Discovery | 2026 R1 Student | Geometry preparation for meshing
Software | Ansys Fluent | 2026 R1 Student | Meshing and CFD digital twin
Software | SolidWorks | 2026 | Design of the tunnel, balance and models

### 3 Results

Wind-tunnel (WT) measurements are compared with two CFD solutions of the confined test section: one that includes the physical model stand (“with stand”) and one of the model alone (“without stand”). Unless stated otherwise, percentage differences are Δ = (WT − CFD)/|CFD| × 100%, and WT uncertainties are the resolution/fluctuation-based estimates of Section 2.5.

### 3.1 Test Conditions

The NACA 4418 was tested at U∞ = 17.5 m/s and the Ahmed body at 16 m/s; the test conditions are listed in Table 3.1.

Table 3.1: Nominal test conditions (ρ = 1.225 kg/m³ ).

Quantity | NACA 4418 | Ahmed body
Reference length | chord c = 100 mm | length L = 120 mm
Reference area Aref | 0.0125 m² | 1.48 × 10⁻³ m²
Nominal U∞ | 17.5 m/s | 16.0 m/s
Dynamic pressure q∞ | 187.6 Pa | 156.8 Pa
Reynolds number | ≈ 1.2 × 10⁵
| (on c) | ≈ 1.3 × 10⁵ (on L)
Mach number | 0.051 | 0.047
Angles of attack | −5 ◦ , 0 ◦ , 5 ◦
| , 10◦ | 0 ◦

### 3.2 NACA 4418: Aerodynamic Forces

Table 3.2 lists the measured lift and drag coefficients and lift-to-drag ratios together with both CFD solutions; they are plotted in Figs. 3.1 and 3.2.

Table 3.2: NACA 4418 force coefficients: wind tunnel (WT) vs. CFD with and without the model stand. Δ = (WT−CFD)/|CFD|.

| Wind tunnel | CFD (with stand) | CFD (without stand)
α | Value | ± | Value | Δ (%) | Value | Δ (%)

Cl

−5

- | −0.0624 | 0.0130 | −0.0717 | +13.0 | −0.101 | +38.0
0
- | 0.176 | 0.0161 | 0.177 | −0.7 | 0.173 | +1.6
5
- | 0.354 | 0.0238 | 0.417 | −15.1 | 0.416 | −14.8
10◦ | 0.612 | 0.0372 | 0.762 | −19.7 | 0.707 | −13.4

Cd

−5

- | 0.0636 | 0.0131 | 0.0723 | −12.0 | 0.0390 | +63.0
0
- | 0.0753 | 0.0133 | 0.0734 | +2.6 | 0.0418 | +80.2
5
- | 0.0912 | 0.0136 | 0.0854 | +6.8 | 0.0656 | +39.1
10◦ | 0.155 | 0.0154 | 0.142 | +9.1 | 0.128 | +21.6

Cl/Cd

−5

- | −0.981 | 0.276 | −0.992 | +1.1 | −2.58 | +62.0
0
- | 2.33 | 0.423 | 2.41 | −3.2 | 4.14 | −43.6
5
- | 3.88 | 0.552 | 4.88 | −20.5 | 6.34 | −38.8
10◦ | 3.95 | 0.330 | 5.36 | −26.3 | 5.54 | −28.8

Lift. At 0

◦
the measured lift coefficient agrees with the with-stand CFD to within 0.7% (Cl = 0.176 vs. 0.177). At −5

◦
the measured value is 13% smaller in magnitude, and at 5

◦

and 10◦
it falls 15.1% and
19.7% below the with-stand CFD; at these two angles the gap (0.063 and 0.150) is 2.6 and 4.0 times the WT uncertainty. Including the stand changes the predicted lift little at 0

◦
and 5

◦
(under 3%) but raises it

by 8% at 10◦
and reduces its magnitude by 29% at −5

◦
. Linear interpolation between −5

◦
and 0
- gives a
zero-lift angle of −3.7

◦
for the WT and −3.6

◦
for the with-stand CFD. Between 0

◦–5

◦
and 5

◦–10◦
the
lift-curve slope increases in both data sets, from 0.036 to 0.052/

◦
(WT) and from 0.048 to 0.069/

◦
(CFD
with stand).

Drag. The measured drag agrees with the with-stand CFD at every angle within the WT uncertainty, with differences of −12.0% to +9.1%. Against the stand-free CFD the WT drag is 22–80% higher; the absolute excess is nearly constant, ΔCd = 0.025–0.034 (mean 0.028), whereas the stand increment predicted by CFD (with-stand minus without-stand) decreases with angle from 0.033 at −5

◦
to 0.014 at
10◦

Lift-to-drag ratio. At −5

◦
and 0

◦
the measured Cl/Cd matches the with-stand CFD within 3.2% (Fig. 3.2). At higher angles the measured ratio levels off, from 3.88 at 5

◦

to 3.95 at 10◦
, while the
with-stand CFD keeps rising (4.88 to 5.36), leaving the WT 20–26% lower. The stand-free CFD, lacking the stand drag, predicts a much higher ratio that peaks at 5

◦
(6.34).

Angle of attack, , (°
)
-5 | 0 | 5 | 10

Lift coefficient, Cl

-0.2

0

0.2

0.4

0.6

0.8
Wind tunnel
CFD (with stand)
CFD (without stand)
(a) Lift coefficient

Angle of attack, , (°
)
-5 | 0 | 5 | 10

Drag coefficient, Cd

0

0.02

0.04

0.06

0.08

0.1

0.12

0.14

0.16

0.18
Wind tunnel
CFD (with stand)
CFD (without stand)
(b) Drag coefficient

Figure 3.1: NACA 4418 force coefficients vs. angle of attack: wind tunnel (error bars: estimated uncertainty) and CFD with and without the model stand.

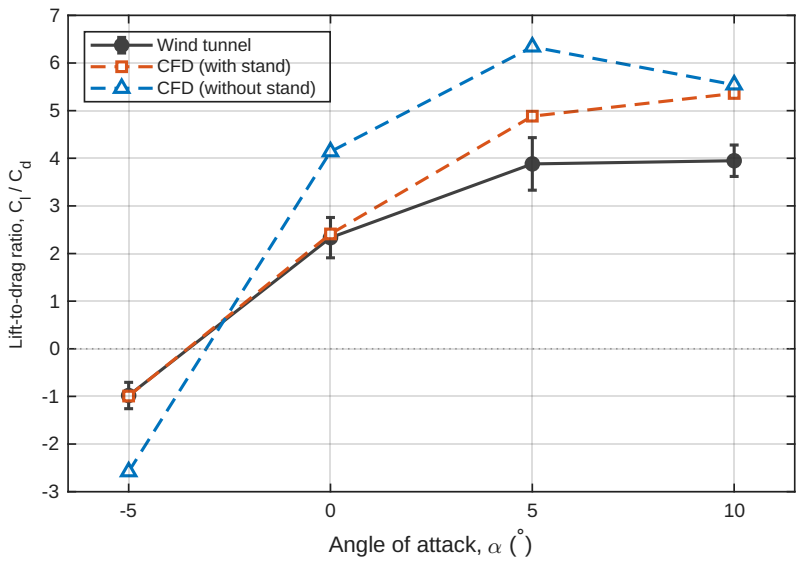
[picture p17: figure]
Angle of attack, , (; Lift-to-drag ratio, Cl; Wind tunnel CFD (with stand) CFD (without stand)

Figure 3.2: NACA 4418 lift-to-drag ratio vs. angle of attack.

### 3.3 NACA 4418: Surface Pressure Distributions

Figure 3.3 compares the measured tap pressures with the continuous with-stand CFD distribution on the tap plane at each angle; Fig. 3.4 regroups the same tap data by surface to show the effect of angle of attack. The differences at each tap are listed in Table 3.3, and the full measured and computed tap values in Section C. The faulty lower tap at x/c = 0.68 is excluded.
The measured distributions reproduce the CFD shapes and their change with angle of attack: upper-surface suction grows and lower-surface suction decreases as α increases, and the suction peak sits at the same tap as in the CFD (the x/c = 0.20 upper tap at 0

◦
and 5

◦

, the leading upper tap at 10◦ , and the
leading lower tap at −5

◦
). In magnitude, however, the WT reads less suction (higher Cp) than the CFD at 23 of the 28 taps; the exceptions are the leading upper tap at −5

◦
and 0

◦
and the three lower taps at 10◦
. Only 3 of the 28 differences lie within the WT uncertainty. The gap is largest where the suction is strongest: 0.19–0.25 at the suction-peak tap for −5

◦
to 5

◦
, rising to 0.45–0.51 at the two leading upper taps at 10◦
. The rearmost upper tap (x/c = 0.75) reads 0.16–0.23 less suction than the CFD at every angle. On the lower surface at 10◦
the WT shows slight suction (Cp = −0.05 to −0.11) where the CFD predicts small positive pressures (+0.01 to +0.17), i.e. the sign of Cp differs.

Table 3.3: NACA 4418 tap pressure difference C

WT
p − C

CFD

| p

(CFD with stand); WT uncertainty in parentheses. Positive values mean the WT Cp is higher (less suction) than the CFD. Entries within the WT uncertainty are marked ∗ .

Surface | x/c | α = −5
- 0
- 5
- 10◦
Upper | 0.05 | −0.056 (0.044) | −0.035 (0.041)∗ | +0.003 (0.106)∗ | +0.510 (0.136)
Upper | 0.20 | +0.176 (0.049) | +0.231 (0.085) | +0.188 (0.117) | +0.451 (0.128)
Upper | 0.45 | +0.155 (0.061) | +0.216 (0.070) | +0.117 (0.084) | +0.216 (0.083)
Upper | 0.75 | +0.158 (0.029) | +0.181 (0.028) | +0.159 (0.027) | +0.233 (0.027)
Lower | 0.12 | +0.249 (0.099) | +0.303 (0.050) | +0.083 (0.030) | −0.219 (0.027)
Lower | 0.27 | +0.197 (0.057) | +0.219 (0.039) | +0.061 (0.032) | −0.146 (0.031)
Lower | 0.52 | +0.096 (0.036) | +0.104 (0.032) | +0.015 (0.030)∗ | −0.114 (0.030)

### 3.4 Ahmed Body

Drag. The measured drag coefficient is Cd = 0.671 ± 0.134, 9.0% above the with-stand CFD (0.616 ± 0.004, 1 SD of the averaged monitor) and within the WT uncertainty (Table 3.4). The stand-free CFD predicts Cd = 0.443, which the WT exceeds by 51.5%.

Table 3.4: Ahmed body drag coefficient. WT ±: estimated uncertainty; CFD ±: 1 SD of the averaged monitor; Δ = (WT − CFD)/|CFD|.

Source | Cd | ± | Δ (%)
Wind tunnel | 0.671 | 0.134 | –
CFD (with stand) | 0.616 | 0.0035 | +9.0
CFD (without stand) | 0.443 | – | +51.5

Surface pressure. Along the upper surface (Fig. 3.5) the WT reproduces every feature of the CFD distribution: the suction peak behind the nose (x/L = 0.05), the recovery to a near-flat roof plateau (x/L ≈ 0.3–0.55), the second suction peak near the roof–slant junction (highest at the x/L = 0.82 tap) and the recovery down the slant. The WT suction is weaker than the CFD at every tap, by 0.14–0.42 in Cp: the difference is largest behind the nose (0.42 and 0.37 at x/L = 0.05 and 0.13), 0.19–0.29 over the slant, and smallest on the roof (0.14–0.15). The ratio WT/CFD varies between taps from 0.19 to 0.61, so the difference is not a pure scaling (a scale-plus-offset fit is examined in Section 4.4).

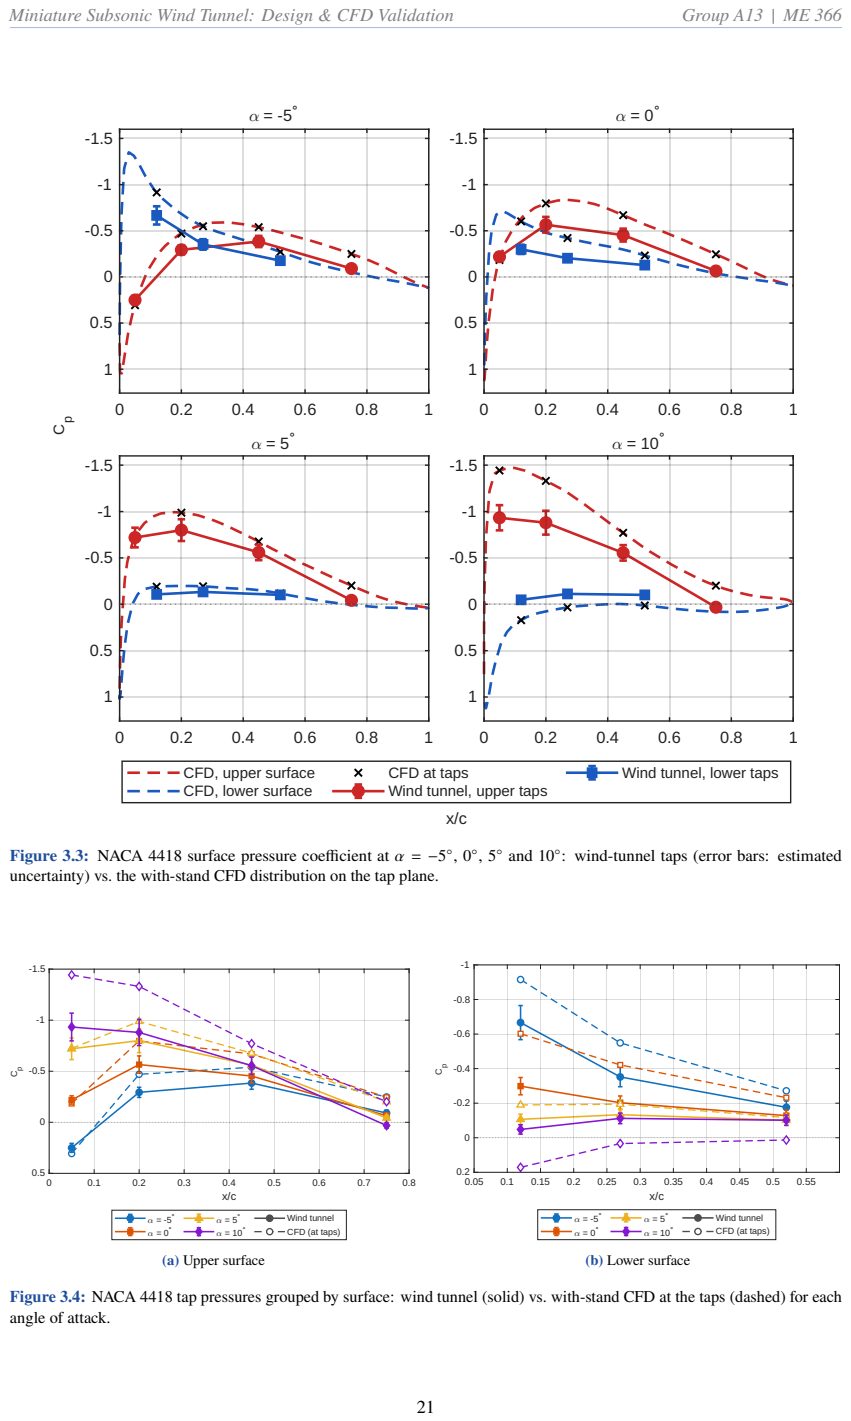
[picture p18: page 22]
and 10◦; (a) Upper surface; (b) Lower surface

CFD, upper surface
CFD, lower surface

CFD at taps
Wind tunnel, upper taps

Wind tunnel, lower taps

Figure 3.3: NACA 4418 surface pressure coefficient at α = −5
uncertainty) vs. the with-stand CFD distribution on the tap plane.

: wind-tunnel taps (error bars: estimated

Wind tunnel
CFD (at taps)

Figure 3.4: NACA 4418 tap pressures grouped by surface: wind tunnel (solid) vs. with-stand CFD at the taps (dashed) for each
angle of attack.

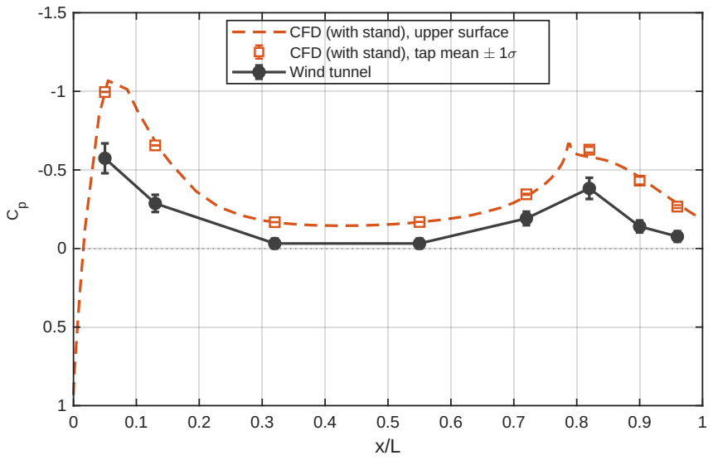
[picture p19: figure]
CFD (with stand), upper surface CFD (with stand), tap mean ' 1< Wind tunnel

Figure 3.5: Ahmed body upper-surface pressure coefficient along its length: wind tunnel vs. with-stand CFD (continuous curve and tap means ±1σ of the averaged solution).

### 3.5 Flow Visualization

Smoke visualization was used as a qualitative demonstration of the facility’s flow-visualization capability, complementing rather than replacing the force and pressure measurements. Representative images of the NACA 4418 at α = 0

◦
and −5

◦
are shown in Fig. 3.6; in both, the smoke rake is at the left and the flow is from left to right. The images were taken at about 5 m/s (Re ≈ 3 × 10⁴ ), well below the speed of the force and pressure tests, so they indicate the flow pattern only qualitatively. At 0

◦
(Fig. 3.6a) the smoke filaments passing over the model follow both surfaces to the trailing edge with no visible separation, consistent with the smooth pressure recovery measured on both surfaces at this angle (Fig. 3.3). At −5

◦
(Fig. 3.6b) the filaments above the model stay close to and follow the upper surface, while below it the smoke does not follow the lower surface and becomes diffuse, suggesting separated or unsteady flow on the lower side. The lower-surface taps, which extend only to x/c = 0.52, still show a steady pressure recovery at this angle, so any such separation would lie further aft.

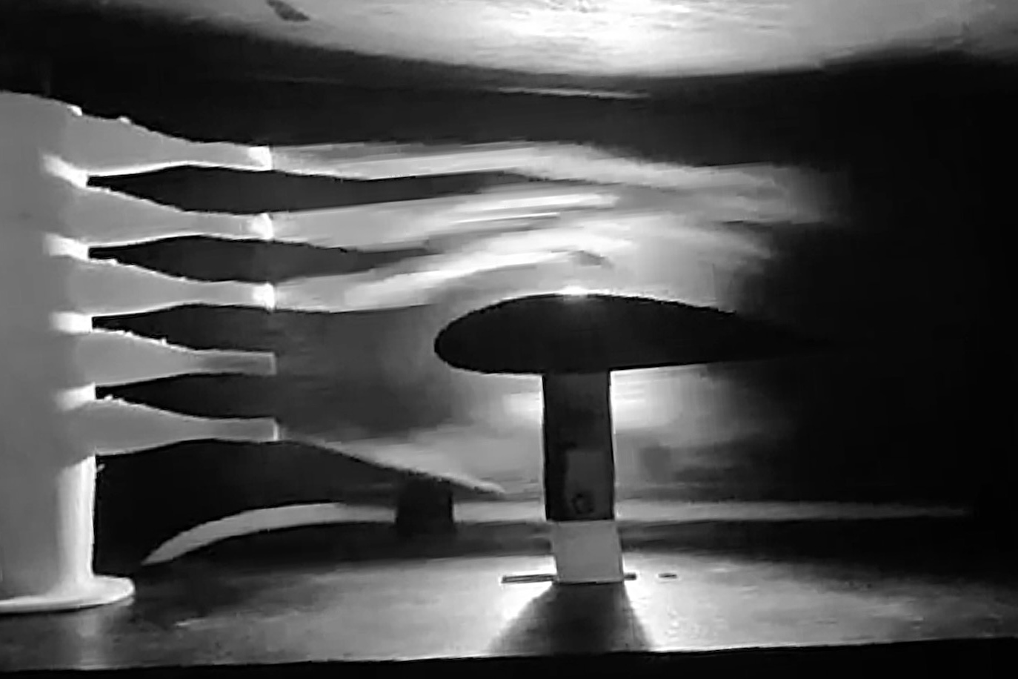
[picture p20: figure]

(a) α = 0

◦

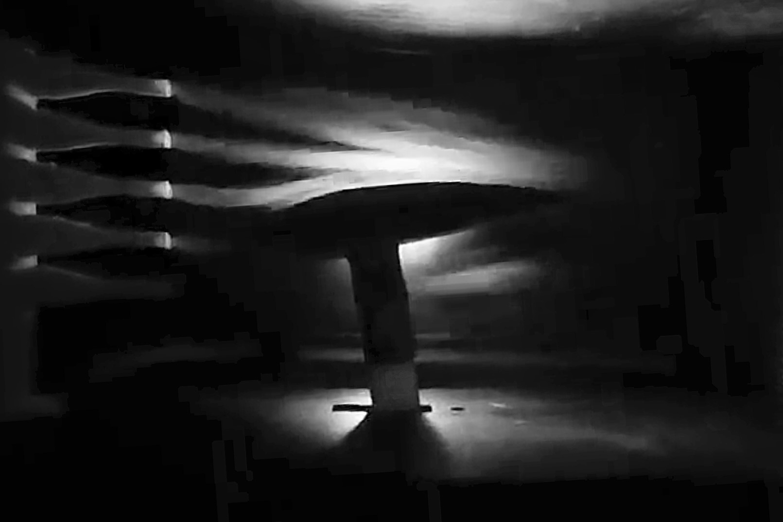
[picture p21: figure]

(b) α = −5

◦

Figure 3.6: Glycerin smoke-rake visualization of the NACA 4418 (flow from left to right). Images converted to grayscale, sharpened for contrast and cropped to a common frame; no other processing.

### 4 Discussion

### 4.1 Overall Agreement with CFD

The tunnel reproduces every trend predicted by the with-stand CFD, while the magnitudes differ by amounts that can largely be traced to identifiable causes. For the NACA 4418, lift at 0

◦
agrees to within
0.7%, the measured drag lies within −12% to +9% of the computed values, and both data sets place the zero-lift angle near −3.7

◦
(WT) and −3.6

◦
(CFD), close to the ≈ −4

◦
expected for a 4%-camber section [7]. Both lift curves steepen between 5

◦

and 10◦
, and the measured pressure distributions keep the CFD shapes and suction-peak locations at every angle. For the Ahmed body, the measured drag coefficient is within 9% of the with-stand CFD, and the pressure distribution reproduces the nose suction peak, roof plateau, roof–slant suction peak and slant recovery. The main departures are a lift deficit at 5

◦

and 10◦
,
drag errors that change sign with angle of attack, and weaker measured suction on both models. These are discussed below.

### 4.2 Drag and Stand Interference

Comparing the two CFD cases isolates the drag added by the stand (sting and mount), including its interference with the model. Table 4.1 lists this increment together with the measured drag in excess of the stand-free CFD.

Table 4.1: Drag added by the stand. CFD increment = C

with stand
d

−C

without stand
d

, also given as a force at the test dynamic pressure and as a share of the with-stand Cd. WT excess = C

WT
d

− C

without stand
d

| CFD stand increment
Case | ΔCd | Force (N) | Share of Cd | WT excess ΔCd | WT − CFD (with stand)

NACA, −5

- | 0.033 | 0.078 | 46% | 0.025 | −0.009
NACA, 0
- | 0.032 | 0.074 | 43% | 0.034 | +0.002
NACA, 5
- | 0.020 | 0.046 | 23% | 0.026 | +0.006
NACA, 10◦ | 0.014 | 0.033 | 10% | 0.027 | +0.013
Ahmed body | 0.173 | 0.040 | 28% | 0.228 | +0.055

The stand is a large part of the measured drag: 43–46% of the with-stand CFD drag at −5

◦
and 0

◦
,
and 28% for the Ahmed body. This is why the measured drag exceeds the stand-free CFD by 22–80% on the NACA 4418 and by 52% on the Ahmed body, while the with-stand CFD agrees to within the WT uncertainty in every case. Modeling the physical support is therefore essential when CFD is used to validate a small tunnel with a sting-mounted model.
The stand’s contribution is not constant in the CFD. Its increment is steady at about 0.032 (0.075 N) for −5

◦
and 0
- but halves by 10◦
(0.033 N). The sting sits below the airfoil, in the flow shaped by its lower surface: at negative incidence that surface accelerates the flow (lower-surface Cp down to −0.9 at −5

◦

), while at 10◦
it decelerates it (Cp > 0), so the sting sees a higher local dynamic pressure at negative angles and a lower one at positive angles. The measured excess over the stand-free CFD, by contrast, is nearly constant at 0.028 ± 0.004 (mean ± SD), a scatter well inside the WT uncertainty. The result is the WT–CFD error trend of Table 3.2: −12% at −5

◦

rising steadily to +9% at 10◦ . (If a constant stand
contribution of 0.028 is instead subtracted from the WT data, the remainder agrees with the stand-free CFD to within −8% to +14%; the present data cannot distinguish the two interpretations, and a direct measurement of the stand alone would settle it.)
A likely cause of this angle-dependent error is the location of the angle-of-attack pivot, about 38 mm below the chord line rather than near the model’s center of gravity. Changing the angle therefore also moves the model forward or aft, and the balance was tared at the set angle before the fan was started. Once the flow is on, the aerodynamic loads act well above the pivot and produce a moment about it that the linkage can pass on to the drag lever, and the model was observed to shift slightly under load, moving its weight away from the tared position. At negative incidence the model leans forward and pulls on the drag lever, lowering the reading; at positive incidence the lift and drag push it into the drag load cell, raising the reading. Because the NACA 4418 is cambered and the loads grow with angle, this bias is neither symmetric about 0
- nor constant, consistent with the measured trend. Calibration adds a second, related error. Each load cell was calibrated once, with one known mass hung vertically (lift) or horizontally (drag) on the empty lever system, while the balance was re-tared at the start of every angle. The tare only resets the zero (the intercept of the calibration line); it does not correct its slope. That slope is valid only if the load reaches the lever system through the same geometry as the calibration weights. Once the model is mounted, moved forward or aft by the angle change and displaced further under load, the point at which its loads and weight act, and hence the effective lever arm, differs from the calibration. The resulting error is a gain error: it scales with the load itself, so it cannot be removed by taring and grows with angle of attack. For the same reason, the one-axis-at-a-time calibration never measured how much of the lift appears on the drag channel and vice versa. A combined-load calibration with the model mounted at each test angle would quantify both effects.

### 4.3 Lift Deficit at Higher Angles of Attack

The measured lift falls 15% and 20% below the with-stand CFD at 5

◦

and 10◦
, 2.6 and 4.0 times the WT uncertainty. Expressed as a lift-curve slope, the WT slope is 0.75 of the CFD slope in both angle intervals (0.036 vs. 0.048 and 0.052 vs. 0.069/

◦
). A deficit that scales with angle in this way points to effects that grow with incidence or load rather than to a fixed offset. Three contributions are likely, and the data cannot separate them.

Low-Reynolds-number boundary-layer behavior. At Re ≈ 1.2 × 10⁵
the boundary layer on a thick cambered section is largely laminar over the forward chord and prone to laminar separation and trailing-edge separation, which reduce the lift-curve slope. The k–ω SST model used here treats the boundary layer as fully turbulent from the leading edge [9], so it keeps the flow attached and over-predicts lift. The weaker measured suction near the trailing edge (the x/c = 0.75 tap reads 0.16–0.23 less suction at every angle) is consistent with a thicker or partly separated boundary layer there. Transition modeling was outside the scope of this project.

Effective angle of attack. After the servo-driven angle mechanism failed, the angle was set by hand against a protractor. At the measured slopes, the lift deficit corresponds to an angle error of about 1

◦
at 5

◦
and about 2

◦

at 10◦
. A setting error of up to a degree is plausible, and the loads, which grow with angle, can also deflect the model slightly away from the set angle once the fan is on (Section 4.2). The direction of that deflection was not measured, but a nose-down rotation would reduce lift in proportion to load, as observed, and would also explain why the 10◦
lower-surface pressures read slight suction where the CFD predicts positive Cp (Section 4.4).

Balance calibration. The lift channel is subject to the same gain error as the drag channel (Section 4.2): the calibration slope was obtained with weights on the empty lever, and the tare at each angle corrects only the zero. Because the forward–aft shift of the model grows with angle, the effective lever arm, and so the true gain, departs further from the calibrated value at higher incidence. An error of this kind is proportional to the load, which matches the uniform 0.75 ratio of the lift-curve slopes. Its size cannot be estimated without a calibration with the model mounted, but it is a plausible contributor alongside the two effects above.
Two further candidates can be ruled out as causes of the WT–CFD difference. Wall confinement and the gaps between the model’s ends and the side walls are present in both, because the CFD domain reproduces the confined test section with no-slip walls. Gravity, omitted in the CFD, only adds a hydrostatic pressure of about 0.5 Pa across the model height (0.3% of q∞) in this incompressible flow, and the model’s weight is removed by the tare.
The lift deficit also explains the L/D behavior: the measured L/D levels off between 5

◦

and 10◦
(3.88
to 3.95) while the CFD value keeps rising, because the measured lift is reduced most at the angle where the measured drag is biased highest.

### 4.4 Surface Pressure Discrepancies

On both models the measured pressure distributions have the right shape but weaker suction than the CFD. On the Ahmed body the relationship is close to linear: a least-squares fit over the eight taps gives

C

WT
p ≈ 0.65C

CFD
p + 0.08 (R

2 = 0.95, residual 0.04, comparable to the WT uncertainty). The measured values are therefore mostly a scaled-down copy of the CFD with a small positive shift. On the NACA 4418 the same fit gives a scale factor that varies with angle (0.59–0.93), and the lower surface departs from the pattern at 10◦
, so a single factor does not describe it. The candidate causes, and what the data say about each, are as follows.

Dynamic pressure. The Cp data were reduced with the nominal test speed, since the single differential sensor measured each tap against the Pitot static port and could not measure q∞ at the same time. An error in q∞ scales every Cp by the same factor. Within the ±1.25 m/s speed uncertainty this gives up to about ±14%, but a factor of 0.65 would need the true speed to be about 80% of the nominal value, roughly 13 m/s for the Ahmed test, which is well below the 16–18.5 m/s observed during the tests. A q∞ error can contribute but cannot explain the full difference.

Reference pressure. The WT pressures are referenced to the Pitot static port, while the CFD Cp uses the solver’s reference pressure. Any difference between these two references shifts every Cp by a constant. The fitted shifts are small (+0.08 for the Ahmed body, about zero for the pooled NACA data), so this effect is minor.

Pressure-line leakage. A leak between a tap and the sensor mixes the tap pressure with the pressure at the leak. If the leak opens into the test section, where the pressure is close to the static reference (Cp ≈ 0), every reading is pulled toward zero by the same fraction, which produces exactly the scaling observed. The NACA 4418 routes each tap through internal 3D-printed channels; one of its lower taps (x/c = 0.68) was unusable, which shows that these channels are not always sealed. The Ahmed body used tubes brought directly to the taps, yet it shows a similar reduction, so the channels are unlikely to be the only path; tube joints and the tube passages through the test-section wall are other candidates. A leak test of each line would confirm or rule this out.

Real aerodynamic differences. On the NACA 4418, part of the Cp difference is physical rather than instrumental. A lower effective angle of attack and a thicker, partly separated low-Re boundary layer (Section 4.3) both weaken the upper-surface suction peak, which is where the largest differences occur (0.45–0.51 at the two leading upper taps at 10◦
). A lower effective angle also explains the sign difference on the lower surface at 10◦
, where the WT reads slight suction and the CFD a small positive pressure. Other effects are smaller. The 4.9 Pa sensor resolution corresponds to ΔCp ≈ 0.03. Air drawn in through unsealed joints and holes in the test section (the induced-draft fan keeps it below atmospheric pressure) may disturb the local flow near some taps.

### 4.5 Limitations

Flow quality. The empty test section reaches about 19 m/s and the speed fluctuates by roughly ±1.25 m/s, but the spatial uniformity and turbulence intensity of the flow were not measured. Several features of the build could degrade them. Some straws in the honeycomb were squashed into elliptical cells during assembly. The screen nearest the model sits at the contraction exit rather than upstream of the contraction, where screens are normally placed [4]: at that position the local dynamic pressure is 6.25² ≈ 39 times higher, so the screen’s pressure loss is correspondingly larger and its wake reaches the test section with little distance to decay. The plywood panel seams are sealed only by external epoxy fillets, and the flanged joints between sections and the window joint have no gaskets; air leaks in through these joints and through holes in the test section.

Wall effects. The model blocks about 10% of the test-section area (stand included). No blockage correction was applied [5]. Because the CFD reproduces the confined test section, the WT–CFD comparison is unaffected, but the coefficients reported here are confined-flow values and cannot be compared directly with free-air data.

Measurements. The fan speed was set with an open-loop regulator, without feedback control, and drifted between about 16 and 18.5 m/s. The Cp data were reduced with the nominal speed rather than a simultaneously measured one. All coefficients are normalized with the reference density ρref = 1.225 kg/m³

, the value used in the CFD, whereas the tunnel air at about 30 ◦C has ρ ≈ 1.164 kg/m³ .
At a given measured speed this overstates q∞ by about 5% and lowers every WT coefficient by the same fraction. The bias is small compared with the ±14% uncertainty in q∞ for the pressure data, but it accounts for a few percentage points of the lift and suction deficits and slightly lowers the measured drag. The angle of attack was set manually, and small changes (below 1

◦
) noticeably affected the readings. Pressure taps were switched by hand. The force balance was calibrated one axis at a time on the empty levers and re-tared at each angle, which corrects the zero but not the gain; its sensitivity to the model’s position and its cross-coupling are unknown.

3D-printed models and balance. Both models were printed in PLA on a Bambu Lab A1 FDM printer. The printed surfaces carry layer lines and small dimensional errors in the profile, whereas the CFD geometry is exact and hydraulically smooth. At Re ≈ 1.2 × 10⁵
the boundary layer is sensitive to roughness, which can move transition and separation and so change both the pressure distribution and the forces (Section 4.3). Printed tap holes may also be slightly off-normal or have rough edges, which biases the static pressure they sample. The lever arms of the dual-lever balance (rectangular cross-section) and the shafts connecting them to the bearings are also printed in PLA. They can flex slightly under load, and PLA creeps under sustained load, so the lever geometry, and with it the calibration gain, may differ between calibration and testing and drift during a run. Play between the printed shafts and the bearings adds further hysteresis. Stiffer materials (machined aluminum or steel levers and shafts) would remove most of these effects.

CFD. All simulations are steady RANS with k–ω SST. Several cases, especially those with the stand, did not converge in the residuals because the flow is mildly unsteady. They were run until the Cl

, Cd and
key Cp monitors were flat, or, where the monitors oscillated, averaged over whole cycles, with the spread reported as 1 SD. The student license’s cell limit restricted mesh refinement. The 10◦ with-stand case used additional wake refinement, so part of its difference from the stand-free case may be due to the mesh rather than the stand. No mesh-independence study, transient simulation or turbulence-model comparison was carried out.

### 4.6 Challenges Faced and Solutions

Table 4.2 summarizes the main problems met during design, construction, testing and simulation, and how each was resolved.

Table 4.2: Challenges faced and how they were resolved.

Challenge | Problem | Solution
Fan and airflow | Four 185 CFM server fans in parallel, with
closed-loop PID speed control, were planned for at least 10 m/s. They gave only 4–5 m/s: rated airflow applies at zero pressure rise, and the honeycomb, screens and contraction add losses.

Replaced by a 14 in, 350 W induced-draft drum fan (2000+ CFM) and the feedback control was dropped. The tunnel now reaches 16–18 m/s with a model installed.

Contraction cone The fifth-order polynomial profile [6] cannot be formed from plywood, and the cone is too large for a standard 3D printer; several large prints failed.

Printed in eight flanged segments and joined with screws.

Table 4.2 continued

Challenge | Problem | Solution
Flow straightener | A 3D-printed honeycomb would have thick
walls and add blockage.

Built from about 2000 drinking-straw sections cut to length with a hot wire (L/D ≈ 7).

Sealing | Air leaked through the joints between
sections.

Epoxy fillets along the outer panel seams; the flanged joints have no gaskets, so some leakage remains (Section 4.5).

Angle of attack | The cam of the servo-driven angle
mechanism broke.

Angle set manually with a protractor.

Tap selection | A cam-driven pinch-off selector, meant to
open one tube at a time, jammed because of friction between the tubes and the 3D-printed cam.

Taps switched by hand, one tube at a time.

Pressure channels Internal 3D-printed channels in the models were unreliable; one NACA lower tap failed.

The Ahmed body was built with tubes entering directly at the taps.

Balance friction Stiction at the lever pivots prevented readings from returning to zero.

Lever pivots on 624ZZ ball bearings.

Pressure zero drift The sensor’s zero offset drifted between runs.

Automatic tare at the start of every run (fan off, mean of about 100 samples).

Flow visualization A 24 V ultrasonic mist generator produced too little mist to be visible at test speed. Smoke from glycerin-soaked cotton heated with a soldering iron.

CFD reference case Stand-free CFD, representing the ideal model alone, left large gaps in the drag comparison. The stand was added to the CFD geometry, so the with-stand runs act as a digital twin of the actual setup and test the measurement system itself.

CFD post-processing | Force reports picked up tunnel-floor faces; Cp from manually placed points was wrong at some taps.
Each wall zone was checked individually; Cp was read from the tap-plane curve.
CFD convergence and mesh | Steady solutions oscillated instead of converging, and the student cell limit restricted refinement.

Monitors run until flat, or averaged over whole cycles; local sizing at thin trailing edges and junctions, 15–18 boundary layers.

### 5 Conclusion and Future Work

### 5.1 Conclusions

A miniature open-circuit subsonic wind tunnel was designed, built and instrumented from laser-cut plywood, 3D-printed parts and low-cost electronics. With a model installed it runs at 16–18 m/s in a 160 mm × 160 mm test section, giving Re ≈ 1.2 × 10⁵ on a 100 mm chord, and it measures lift, drag, surface pressure and freestream speed, with smoke visualization for qualitative flow observation. The measurements were compared with a CFD digital twin of the confined test section that includes the model’s support stand.
The tunnel captures the aerodynamic trends of both test models. For the NACA 4418, the measured zero-lift angle (−3.7

◦
) is within 0.1
- of the CFD value, the lift at 0

◦
agrees to within 1%, both data sets show the lift-curve slope rising between 5

◦

and 10◦
, and the measured drag lies within −12% to +9% of the with-stand CFD. The measured pressure distributions reproduce the computed shapes and suction-peak positions on both models, and the Ahmed-body drag coefficient is within 9% of the with-stand CFD. The magnitudes differ in three consistent ways, each with likely causes. The measured lift is 15–20% below the CFD at 5

◦

and 10◦
, attributed to low-Reynolds-number boundary-layer behavior that the fully turbulent RANS model does not capture, to the effective angle of attack under load, and to the calibration of the balance. The drag error changes sign with angle of attack, consistent with coupling through the balance pivot. The measured suction is weaker than the CFD on both models, consistent with leakage in the pressure lines and, on the airfoil, with real low-Reynolds-number effects. None of these appears to be random error, so each can be reduced by the improvements below.
The main lesson for small facilities is that the support hardware must be part of the comparison. The stand accounts for 43–46% of the airfoil’s drag at low incidence and 28% of the Ahmed body’s; omitting it from the CFD makes the measured drag appear 22–80% too high, while including it brings the two into agreement within the measurement uncertainty. In a small, confined tunnel, modeling the actual stand and walls matters as much as the choice of turbulence model.

### 5.2 Future Recommendations

Several improvements could make the facility more accurate and easier to use:
1. Stiffer balance. The levers could be machined from metal and the printed shafts replaced by metal pins, so that the balance would not flex or vibrate under load; printing the levers in a tougher, more creep-resistant filament such as PETG would be a simpler intermediate step.
2. Balance calibration. Calibrating with the model mounted at each test angle, and with combined lift and drag loads, would measure the gain and cross-coupling errors directly.
3. Pivot position. New models could be designed with the angle-of-attack pivot close to their center of gravity, so that changing the angle would not shift the load on the balance.
4. Support stand. A thinner, more streamlined stand would add less drag and interference, and measuring the drag of the stand alone would allow its contribution to be subtracted from the balance readings.
5. Sealing. Gaskets between the tunnel sections and between the test section and the window would reduce the air leaking into the test section.
6. Pressure system. The pressure lines could be leak-tested before each run, and a second differential sensor (or a pressure scanner) would allow the dynamic pressure to be measured together with each tap; a 16-bit ADC such as the ADS1115 would give finer pressure resolution.
7. Wall corrections. Blockage corrections [5] would allow the results to be compared with free-air data as well.
8. CFD. Transient simulations with a scale-resolving turbulence model, such as detached-eddy simulation, could resolve the unsteady flow directly instead of relying on averaged steady solutions. A mesh-independence study, a transition-sensitive model and a domain extended upstream to include the screens and contraction would further improve the comparison.

9. Flow visualization. Smaller, smoother smoke nozzles with passive (suction-driven) injection could give cleaner streaks, and all test angles could be recorded.
10. Further models. The circular cylinder, dropped during the project, could be reintroduced as a benchmark with a well-known pressure distribution, and the Ahmed body could be tested at other slant angles.

Data and Code Availability

All files needed to rebuild the tunnel and reproduce the results are openly available in the project’s GitHub repository (link and QR code below). The repository contains:
- SolidWorks 2026 models and assemblies of the tunnel, force balance, test models, Pitot stand and

smoke rake, with DXF files for laser cutting the plywood and acrylic panels;
- the Arduino firmware for the force balance and the surface-pressure survey;
- the MATLAB data-reduction and plotting scripts, together with the experimental coefficient

workbook;
- the Ansys Discovery geometry prepared for meshing and the Ansys Fluent project files (both Ansys

Student 2026 R1), the simulated geometry (STEP), the force and pressure monitor histories, and the tap-plane pressure exports.
The Fluent mesh, case and data files (about 12 GB in total) are not included; they can be regenerated from the Discovery geometry and the settings in Table 2.3. The repository README lists the folder layout and the software versions required.

https://github.com/0xSYNDEED/PROJECT-WIND-TUNNEL

Acknowledgments

We are grateful to Dr. Kazi Arafat Rahman, Associate Professor, and to Md Moyeenul Hossain Ratul, Rafiul Haq and Dilshad Jahan Ritu, Lecturers, Department of Mechanical Engineering, BUET, for their guidance and support throughout this project.

References

[1] T. J. Mueller and J. D. DeLaurier, “Aerodynamics of small vehicles,” Annual Review of Fluid Mechanics, vol. 35, pp. 89–111, 2003.
[2] P. B. S. Lissaman, “Low-Reynolds-number airfoils,” Annual Review of Fluid Mechanics, vol. 15, pp. 223–239, 1983.
[3] Ismail, E. A. Pane, and R. A. Rahman, “An open design for a low-cost open-loop subsonic wind tunnel for aerodynamic measurement and characterization,” HardwareX, vol. 12, p. e00352, 2022.
[4] R. D. Mehta and P. Bradshaw, “Design rules for small low speed wind tunnels,” The Aeronautical Journal, vol. 83, no. 827, pp. 443–449, 1979.
[5] J. B. Barlow, W. H. Rae, and A. Pope, Low-Speed Wind Tunnel Testing. New York: Wiley, 3rd ed., 1999.

[6] J. H. Bell and R. D. Mehta, “Contraction design for small low-speed wind tunnels,” NASA Contractor Report NASA-CR-182747 (JIAA TR-84), Stanford University, for NASA Ames Research Center, Apr. 1988.
[7] I. H. Abbott and A. E. von Doenhoff, Theory of Wing Sections. New York: Dover Publications, 1959.
[8] S. R. Ahmed, G. Ramm, and G. Faltin, “Some salient features of the time-averaged ground vehicle wake,” SAE Technical Paper 840300, SAE, 1984.
[9] F. R. Menter, “Two-equation eddy-viscosity turbulence models for engineering applications,” AIAA Journal, vol. 32, no. 8, pp. 1598–1605, 1994.
[10] ANSYS, Inc., Canonsburg, PA, Ansys Fluent Theory Guide, Release 2026 R1, 2026.
[11] International Engineering Alliance, “Graduate attributes and professional competencies, version 2021.1.” https://www.ieagreements.org, 2021.
[12] “APM airspeed pitot tube for ArduPilot/ArduPlane.” Robotics Bangladesh (RoboticsBD), product page. https://store.roboticsbd.com/speed-detection-sensor-robotics-bangladesh/3490-apm-airspeed-pitot-tube-for-ardupilot-arduplane-robotics-banglades h.html. (https://store.roboticsbd.com/speed-detection-sensor-robotics-bangladesh/3490-apm-airspeed-pitot-tube-for-ardupilot-arduplane-robotics-bangladesh.html)
[13] Arduino, “Arduino mega 2560 rev3 — product documentation.” https://docs.arduino.cc/hardware/mega-2560/, (https://docs.arduino.cc/hardware/mega-2560/) accessed 30 Sep 2026.
[14] NXP Semiconductors, “MPXV7002 integrated silicon pressure sensor, on-chip signal conditioned, temperature compensated and calibrated — data sheet, rev. 5,” 2021. https://www.nxp.com/docs/en/data-sheet/MPXV7002.pdf, (https://www.nxp.com/docs/en/data-sheet/MPXV7002.pdf) accessed 30 Sep 2026.
[15] Avia Semiconductor, “HX711 24-bit analog-to-digital converter (ADC) for weigh scales— data sheet.” https://cdn.sparkfun.com/datasheets/Sensors/ForceFlex/hx711_english.pdf, accessed 30 Sep 2026.

A Fabrication and Assembly Sequence

The facility was fabricated and assembled in the sequence below. Dimensions are given in Section 2 and the parts in Table 2.4; the CAD models (including the Pitot holder and smoke rake), DXF cutting files, firmware and scripts are in the project repository (see Data and Code Availability).

1. Tunnel panels. The plywood panels, square flanges and acrylic window were laser-cut from the DXF files, which include all screw holes and the test-section openings: a rectangular slot in the floor for the model stand, two 20 mm floor holes for the Pitot holder and the visualization lighting, and holes in the wall opposite the window for the tap tubes. The panels were bonded with cyanoacrylate into the settling chamber, test section and diffuser, and their seams were strengthened with epoxy fillets. The 6 mm acrylic window is screwed to the flanges along the top and bottom of the test section and can be removed.
2. Contraction. The eight flanged contraction segments were printed in PLA and screwed together. The gaps between them were sealed by pouring in epoxy, and the inner surface was coated with epoxy to smooth the rough finish of the large prints.
3. Honeycomb. Just over 1000 bubble-tea straws were cut in half with a hot wire to 70 mm lengths, and the resulting ∼2000 sections were packed into the settling chamber (Fig. 2.3a).
4. Screens. Three 2 mm wire-mesh screens were fitted: at the settling-chamber exit, at the contraction exit (with a hole for the Pitot probe) and at the test-section exit, ahead of the diffuser.
5. Tunnel assembly. The settling chamber, contraction, test section and diffuser were joined at their flanges with M3 and M4 screws. The diffuser exit was coupled to the fan with the tarpaulin sleeve, tightened with metal cable ties and rope, and the fan was powered through the SCR regulator.
6. Force balance. The levers, link, stand and supports were printed in PLA, and the four 624ZZ bearings were pressed in: two at the lift-lever pivot, one at the drag-lever pivot and one at the stand–link joint. The two load cells were mounted on their supports, and the balance was placed beneath the test section with the stand passing through the floor slot without touching it (Fig. 2.5).
7. Instrumentation. The load cells were wired to the two HX711 amplifiers, and the amplifiers and the MPXV7002DP pressure sensor to the Arduino Mega (Fig. 2.6). The Pitot probe was fitted in its printed holder, whose base plug closes the 20 mm floor hole and carries the probe’s two tubes out of the test section (Fig. 2.3). The static-pressure tube was connected permanently to the sensor’s reference port; the total-pressure tube was connected to the positive port only when the freestream speed was measured (Section 2.4).
8. Models. The NACA 4418 and Ahmed-body models were printed in PLA with four wall loops, to keep the tap channels airtight. Each model has nozzles on its side, included in the CAD, to which the silicone tubes are attached for the surface-pressure tests (Section 2.4).

B Key Code Excerpts

The listings below are short excerpts of the data-acquisition firmware (LiftDrag_V2.ino, C++ for the Arduino Mega) and of the MATLAB data-reduction scripts, chosen because the methods in Section 2 depend on them. Some lines are condensed and unrelated lines are replaced by ...; the complete files are in the project repository (see Data and Code Availability).

Load-cell calibration and tare. Each channel is calibrated by a least-squares line through the recorded (raw reading, mass) points (here two: zero load and one known mass), and only the slope is stored. The tare at the start of each test re-sets the intercept so that the current reading becomes zero; it does not change the slope, which is the limitation discussed in Section 4.2.

Listing B.1: Least-squares calibration slope and tare intercept (LiftDrag_V2.ino, excerpt; full code in the repository).

1 | // runCalibration(): straight -line fit of mass [g] against raw HX711 counts
2 | float denom = pointCount * sumX2 - sumX * sumX;
3 | calculatedSlope | = ( pointCount * sumXY - sumX * sumY) / denom;
4 | calculatedIntercept = (sumY - calculatedSlope * sumX) / pointCount ;
5 | ...
6 | // doLoadCellTare(): intercept = -slope * rawTare | => | mass = 0 at the tared reading
7 | interceptLift = -slopeLift * rawTareLift ;
8 | interceptDrag = -slopeDrag * rawTareDrag ;

Tap pressures from the CFD tap-plane curve. Fluent exports the pressure coefficient along the tap plane as scattered points. The script finds the leading and trailing edges, rotates the points into the chord frame (which handles every angle of attack the same way), splits them into upper and lower surfaces, and interpolates at the tap positions.

Listing B.2: Chord-frame split of the tap-plane curve and interpolation at the taps (NACA_Cp_Plots.m, excerpt; full code in the repository).

1 | x | = T{: ,2}; | y = T{: ,3}; | cp = T{: ,5}; | % columns: node , x, y, z, Cp
2 | [~, iTE] = max(x); | % TE = most downstream point
3 | d2 = (x - x(iTE)).^2 + (y - y(iTE)).^2;
4 | [~, iLE] = max(d2); | % LE = farthest point from TE
5 | c | = sqrt(d2(iLE));
6 | ch = [x(iTE) - x(iLE), y(iTE) - y(iLE)] / c; | % unit chord
7 | nh = [-ch (2) , ch (1) ]; | % unit normal , upper side positive
8 | xc | = ((x - x(iLE))*ch (1) + (y - y(iLE))*ch (2)) / c; | % x/c along the chord
9 | side = | (x - x(iLE))*nh (1) + (y - y(iLE))*nh (2);
10 | up | = side >= 0; | lo = ~up;
11 | [xu , cpu] = cleanSort (xc(up), cp(up)); | % sort , merge duplicate x
12 | [xl , cpl] = cleanSort (xc(lo), cp(lo));
13 | tapCpU = interp1(xu , cpu , tapU); | % CFD Cp at the tap positions
14 | tapCpL = interp1(xl , cpl , tapL);

Averaging a limit cycle. For the stand-free 10◦
case (Fig. 2.8), each cycle of the drag coefficient has two unequal peaks, so cycles are marked by the taller peak. All monitors are averaged over the last four whole cycles, so that the window starts and ends at the same phase, and the mean is accepted only if it changes by less than 0.5% between the last two and the last four cycles.

Listing B.3: Whole-cycle averaging of a limit-cycle solution (AoA10_OscillationAverage.m, excerpt; full code in the repository).

1 | cd | = Y(: ,1); | | | % drag -coefficient monitor
2 | isPk = islocalmax (cd,’MinProminence’,0.002 ,’MinSeparation’,30) & it > skip;
3 | pk | = find(isPk);
4 | tall = pk(cd(pk) > mean(cd(pk))); | % one marker per cycle
5 | n | = min(nUse , numel(tall) - 1);
6 | w | = tall(end-n) : tall(end) -1; | % whole cycles , same phase at both
| | ends
7 | mu | = mean(Y(w ,:)); | sd = std(Y(w ,:)); | % reported mean and spread
8 | nh | = max(1, floor(n/2)); | wh = tall(end-nh) : tall(end) -1;
9 | shiftPct = abs(mean(Y(wh ,1:2)) - mu (1:2)) ./ abs(mu (1:2)) * 100; | % must be < 0.5 %

Averaging an irregular oscillation. The Ahmed body’s slant pressures oscillated without a clear period, so cycles cannot be counted. The monitors are instead averaged over a fixed window after the start-up transient, and the window is accepted if the means of its two halves agree.

Listing B.4: Fixed-window averaging with a settling check (Ahmed_CFD_Oscillation_Handling.m, excerpt; full code in the repository).

1 | w | = it >= i1 & it <= i2; | % window after the transient
2 | iw | = find(w);
3 | Yw | = Y(w ,:);
4 | mu | = mean(Yw) ’; | sd = std(Yw) ’; | % mean and spread of Cd and the 8 tap Cp
5 | h | = floor(numel(iw)/2); | % has the mean settled? compare the two halves
6 | m1 | = mean(Y(iw (1:h) ,:)); | m2 = mean(Y(iw(h+1:end) ,:));
7 | fprintf(’Cd mean shift between halves: %.2f%%\n’, abs(m2 (1) -m1 (1))/abs(m1 (1))*100);
8 | fprintf(’Max Cp mean shift between halves: %.4f\n’, max(abs(m2 (2:end)-m1 (2:end))));

Uncertainty propagation. The wind-tunnel error bars follow Eq. (4). For L/D the dynamic pressure cancels, so only the force terms remain.

Listing B.5: Uncertainty of the force and pressure coefficients (NACA_Force_Plots.m and NACA_Cp_Plots.m, excerpts; full code in the repository).

1 | % force coefficients (NACA_Force_Plots.m)
2 | q | = 0.5* rho*U^2; | dq_q = 2*dU/U;
3 | dL | = dL_g /1000* gAcc; | dD | = dD_g /1000* gAcc; | % force resolution [N]
4 | L | = M.Cl*q*A; | D | = M.Cd*q*A;
5 | dCl | = sqrt((dL/(q*A))^2 + (M.Cl*dq_q).^2);
6 | dCd | = sqrt((dD/(q*A))^2 + (M.Cd*dq_q).^2);
7 | dLD | = abs(LD(: ,1)) .* sqrt((dL./L).^2 + (dD./D).^2);
8 | % pressure coefficients (NACA_Cp_Plots.m)
9 | dCpFun = @(cp) sqrt((dp/q)^2 + (cp *2* dU/U).^2);

C NACA 4418 Surface Pressure Data

Measured and computed (CFD with stand) pressure coefficients at each tap, with the WT uncertainty of Section 2.5. The faulty lower tap at x/c = 0.68 is omitted.

Table C.1: NACA 4418 tap pressure coefficients: wind tunnel vs. CFD (with stand).

α | Surface | x/c | CWT
p | ± | C

CFD
p | WT−CFD

−5

◦

Upper | 0.05 | 0.251 | 0.044 | 0.306 | −0.056
Upper | 0.20 | −0.293 | 0.049 | −0.470 | +0.176
Upper | 0.45 | −0.384 | 0.061 | −0.539 | +0.155
Upper | 0.75 | −0.091 | 0.029 | −0.249 | +0.158
Lower | 0.12 | −0.666 | 0.099 | −0.915 | +0.249
Lower | 0.27 | −0.352 | 0.057 | −0.549 | +0.197
Lower | 0.52 | −0.176 | 0.036 | −0.272 | +0.096

0

◦

Upper | 0.05 | −0.219 | 0.041 | −0.184 | −0.035
Upper | 0.20 | −0.565 | 0.085 | −0.796 | +0.231
Upper | 0.45 | −0.453 | 0.070 | −0.669 | +0.216
Upper | 0.75 | −0.064 | 0.028 | −0.245 | +0.181
Lower | 0.12 | −0.298 | 0.050 | −0.602 | +0.303
Lower | 0.27 | −0.203 | 0.039 | −0.421 | +0.219
Lower | 0.52 | −0.128 | 0.032 | −0.232 | +0.104

5

◦

Upper | 0.05 | −0.720 | 0.106 | −0.723 | +0.003
Upper | 0.20 | −0.800 | 0.117 | −0.988 | +0.188
Upper | 0.45 | −0.560 | 0.084 | −0.677 | +0.117
Upper | 0.75 | −0.043 | 0.027 | −0.202 | +0.159
Lower | 0.12 | −0.107 | 0.030 | −0.190 | +0.083
Lower | 0.27 | −0.133 | 0.032 | −0.194 | +0.061
Lower | 0.52 | −0.101 | 0.030 | −0.117 | +0.015

10◦

Upper | 0.05 | −0.933 | 0.136 | −1.443 | +0.510
Upper | 0.20 | −0.880 | 0.128 | −1.331 | +0.451
Upper | 0.45 | −0.554 | 0.083 | −0.770 | +0.216
Upper | 0.75 | 0.032 | 0.027 | −0.201 | +0.233
Lower | 0.12 | −0.048 | 0.027 | 0.171 | −0.219
Lower | 0.27 | −0.112 | 0.031 | 0.034 | −0.146
Lower | 0.52 | −0.101 | 0.030 | 0.013 | −0.114

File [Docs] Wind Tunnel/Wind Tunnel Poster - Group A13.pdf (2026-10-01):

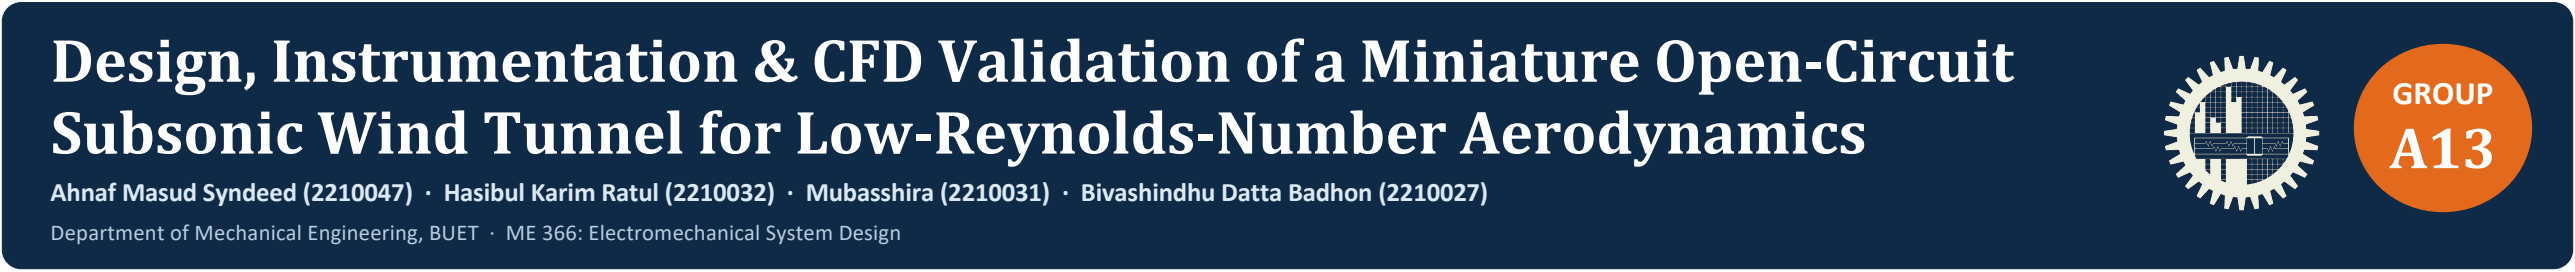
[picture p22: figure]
GROUP A13

# Design, Instrumentation & CFD Validation of a Miniature Open-Circuit Subsonic Wind Tunnel for Low-Reynolds-Number Aerodynamics

Ahnaf Masud Syndeed (2210047) · Hasibul Karim Ratul (2210032) · Mubasshira (2210031) · Bivashindhu Datta Badhon (2210027)

### Department of Mechanical Engineering, BUET · ME 366: Electromechanical System Design

# Motivation & objectives

## Low-Reynolds-number aerodynamic data is scarce for UAVs and ground vehicles. We built a modular, low-cost tunnel for

rapid physical validation of airfoils and bluff bodies.

## - Design and fabricate a subsonic wind tunnel - Measure lift, drag and surface pressure on two models - Validate the measurements against Ansys Fluent, including the model’s mounting stand - Visualize flow attachment and separation

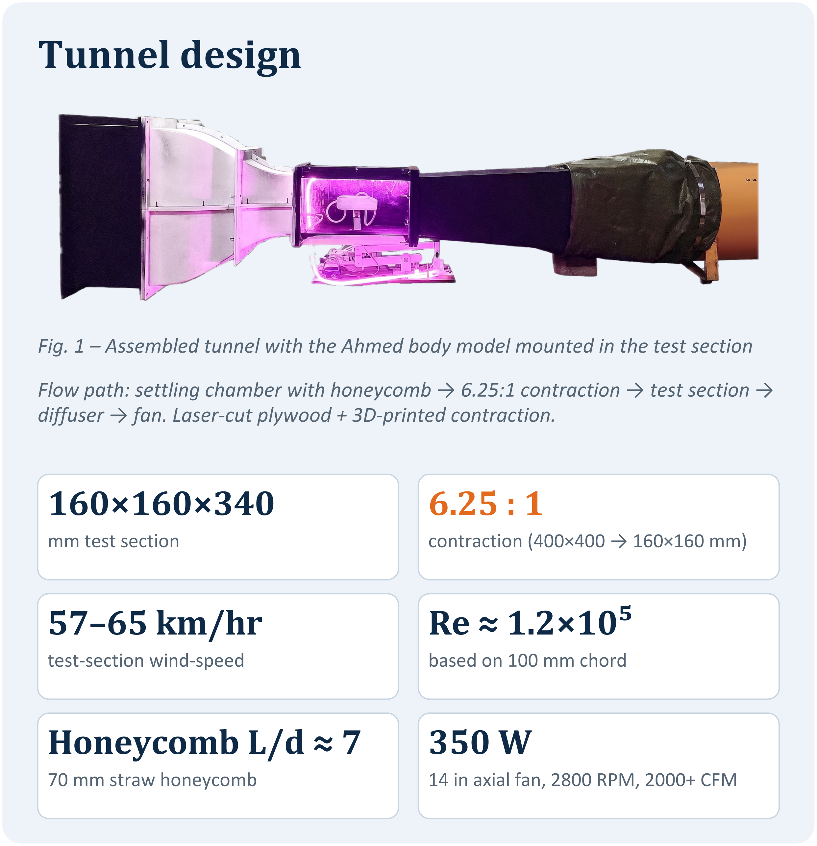
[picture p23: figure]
Tunnel design; mm test section; contraction (400×400 → 160×160 mm); test-section wind-speed; based on 100 mm chord; Honeycomb L/d ≈ 7; 70 mm straw honeycomb; 14 in axial fan, 2800 RPM, 2000+ CFM

Fig. 1 – Assembled tunnel with the Ahmed body model mounted in the test section Flow path: settling chamber with honeycomb → 6.25:1 contraction → test section → diffuser → fan. Laser-cut plywood + 3D-printed contraction.

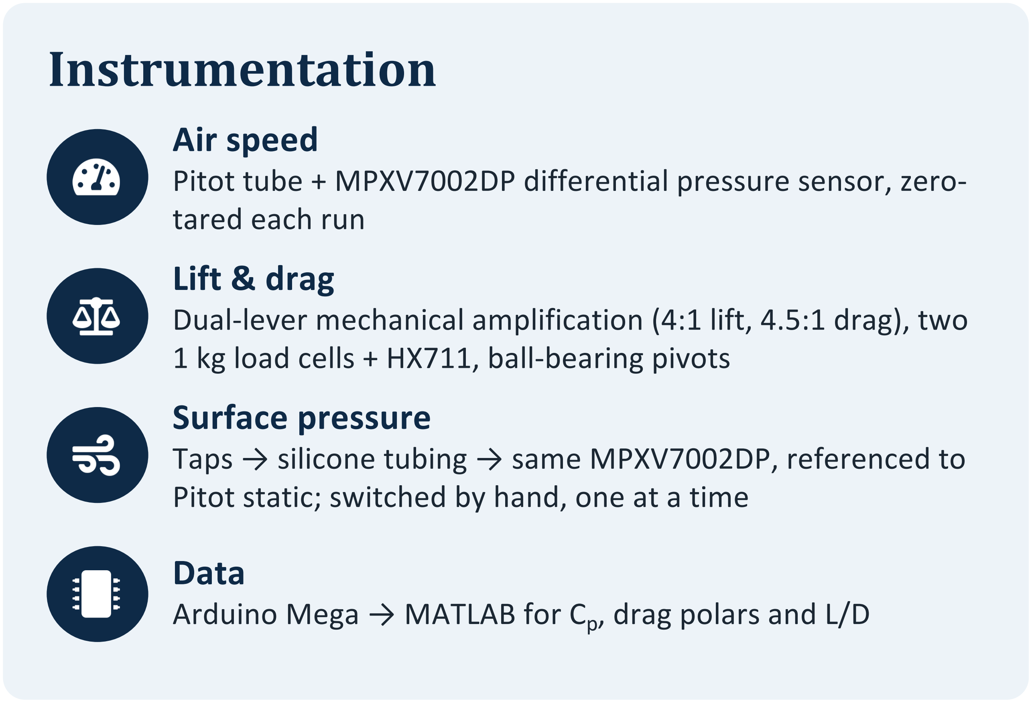
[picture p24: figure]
Instrumentation; Air speed; tared each run Lift & drag; Surface pressure; Data

Pitot tube + MPXV7002DP differential pressure sensor, zero-

Dual-lever mechanical amplification (4:1 lift, 4.5:1 drag), two 1 kg load cells + HX711, ball-bearing pivots

Taps → silicone tubing → same MPXV7002DP, referenced to Pitot static; switched by hand, one at a time

Arduino Mega → MATLAB for Cp, drag polars and L/D

# Test models

Fig. 2a – NACA 4418 airfoil
NACA 4418 airfoil
100 mm chord, 125 mm span
4 upper + 3 lower surface pressure taps Ref. area 0.0125 m²

Fig. 2b – Ahmed body
Modified Ahmed body
120 × 40 × 37 mm, 25° rear slant 8 upper-surface pressure taps Ref. area 1.48×10⁻³ m²

# CFD setup (Ansys Fluent)

### - Steady RANS, k-ω SST; Fluent 2026 R1 Student - Real test-section dimensions with “no-slip” tunnel walls, and the model stand included in one run, excluded in another - 15–18 prism layers, y⁺ ≈ 1.7; oscillating cases averaged over limit cycles - Coefficients (Cl

### , Cd, Cp) compared, not raw forces/pressures

Results: pressure & force | Experiment vs CFD (Ansys Fluent, k-ω SST)


Fig. 3a – NACA 4418 surface Cp vs x/c, WT vs CFD at 5° and 10° AoA | Fig. 3b – Ahmed body surface Cp along its length, WT vs CFD

Fig. 3c – NACA 4418 L/D vs AoA — WT vs CFD (with stand) vs CFD (no stand)

# CFD validation

Case | Coeff. | Exp. | CFD | Δ vs CFD
NACA 0° | Cl | 0.176 | 0.177 | −0.7%
| Cd | 0.075 | 0.073 | +2.6%
NACA +5° | Cl | 0.354 | 0.417 | −15.1%
| Cd | 0.091 | 0.085 | +6.8%
NACA +10° | Cl | 0.612 | 0.762 | −19.7%
| Cd | 0.155 | 0.142 | +9.1%
NACA −5° | Cl | −0.062 | −0.072 | +13.0%
| Cd | 0.064 | 0.072 | −12.0%
Ahmed body | Cd | 0.671 | 0.616 | +9.0%

Δ = (Exp − CFD)/ CFD . Green: within 10%. CFD includes the model stand. At 5° and 10° the lift gap is 2.6–4× the uncertainty: low-Re boundary-layer effects SST misses, effective AoA under load and balance calibration.

≤ 3%

lift and drag agreement with CFD at 0° AoA once the stand is modeled in CFD. Errors increase considerably with higher AoA

With stand-free CFD: drag +80%

# Flow visualization (Qualitative Analysis)


Fig. 4a – NACA 4418, -5° AoA. Glycerin smoke rake. Fig. 4b – Ahmed body (preliminary). Older smoke system; not yet re-run on the upgraded rig.

- Glycerin fog/smoke rake shows attachment, separation and wake structure
- Used qualitatively alongside the Cp and force data
- NACA: attached on both surfaces at 0°; at −5° the lower-surface smoke turns diffuse
- Ahmed body: preliminary run only; its 25° slant is below the ~30° critical angle

# Key conclusions

- Tunnel: 16–18 m/s (Re ≈ 1.2×10⁵) in a 160×160 mm test section behind a 6.25:1 contraction
- NACA @ 0° AoA: with the stand modeled, lift and drag agree with CFD within 3%; without the stand in CFD the gap grows to +80%
- NACA @ +5°, +10° AoA: measured lift 15–20% below CFD: low-Re boundary layer, effective AoA under load, balance calibration
- NACA Pressure: Cp shapes and suction peaks match CFD; suction is weaker, mainly from pressure-line leakage
- Ahmed body: drag 9% above CFD (within uncertainty). Cp reproduces every CFD feature, with weaker suction (≈ 0.65 × CFD).

# Future work

### - Stand-only tare run to isolate model drag - Blockage correction (~10%) - 16-bit ADC (e.g. ADS1115), more taps - Repeatable AoA setting; refined smoke rake - Model-mounted, combined-load calibration

Acknowledgments
We thank Associate Prof. Dr. Kazi Arafat Rahman, Lect. Md Moyeenul Hossain Ratul, Lect. Rafiul Haq and Lect. Dilshad Jahan Ritu, and the Department of Mechanical Engineering, BUET, for guidance and lab support.

References
[1] S. R. Ahmed et al., SAE 840300, 1984.
[2] I. H. Abbott, A. E. von Doenhoff, Theory of Wing Sections, Dover, 1959.
[3] J. B. Barlow, W. H. Rae, A. Pope, Low-Speed Wind Tunnel Testing, 3rd ed., Wiley, 1999.

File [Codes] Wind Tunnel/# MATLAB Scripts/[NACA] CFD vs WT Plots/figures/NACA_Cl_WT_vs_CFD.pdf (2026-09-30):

A

n

### gle

o

f

a

t

t

a

c

k, ,

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
## Lift coefficient, Cl

0.2

0.10 0.1 0.2 0.3 0.4 0.5 0.6 0.7 0.8
Win

d

t

u

n

n

el CFD (with s
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
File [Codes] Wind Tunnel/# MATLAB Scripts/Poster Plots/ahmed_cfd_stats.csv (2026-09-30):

Quantity | x_L | Mean | StdDev | HalfP2P | Min | Max
Cd | NaN | 0.615908758093535 | 0.00353801781844505 | 0.00739727477843982 | 0.609829122632451 | 0.624623672189331
Cp_t1 | 0.05 | -0.995764083530179 | 0.000233058585735921 | 0.000460386276245117 | -0.996289670467377 | -0.995368897914886
Cp_t2 | 0.13 | -0.656080918525582 | 0.000129267281642979 | 0.000253111124038696 | -0.65633237361908 | -0.655826151371002
Cp_t3 | 0.32 | -0.167670089584678 | 0.000100360036173283 | 0.000288344919681549 | -0.167856618762016 | -0.167279928922653
Cp_t4 | 0.55 | -0.168752945403555 | 0.000499308151930588 | 0.00107462704181674 | -0.169405102729797 | -0.167255848646164
Cp_t5 | 0.72 | -0.344957597368392 | 0.00423855944132486 | 0.0090101957321167 | -0.351746052503586 | -0.333725661039352
Cp_t6 | 0.82 | -0.62877532231867 | 0.0175131276961514 | 0.0375339686870575 | -0.657627403736115 | -0.582559466362
Cp_t7 | 0.9 | -0.432018324213835 | 0.0242054153051785 | 0.0431871116161347 | -0.476466536521912 | -0.390092313289642
Cp_t8 | 0.96 | -0.266560627453363 | 0.00920277747993192 | 0.0214997157454491 | -0.286543667316437 | -0.243544235825539

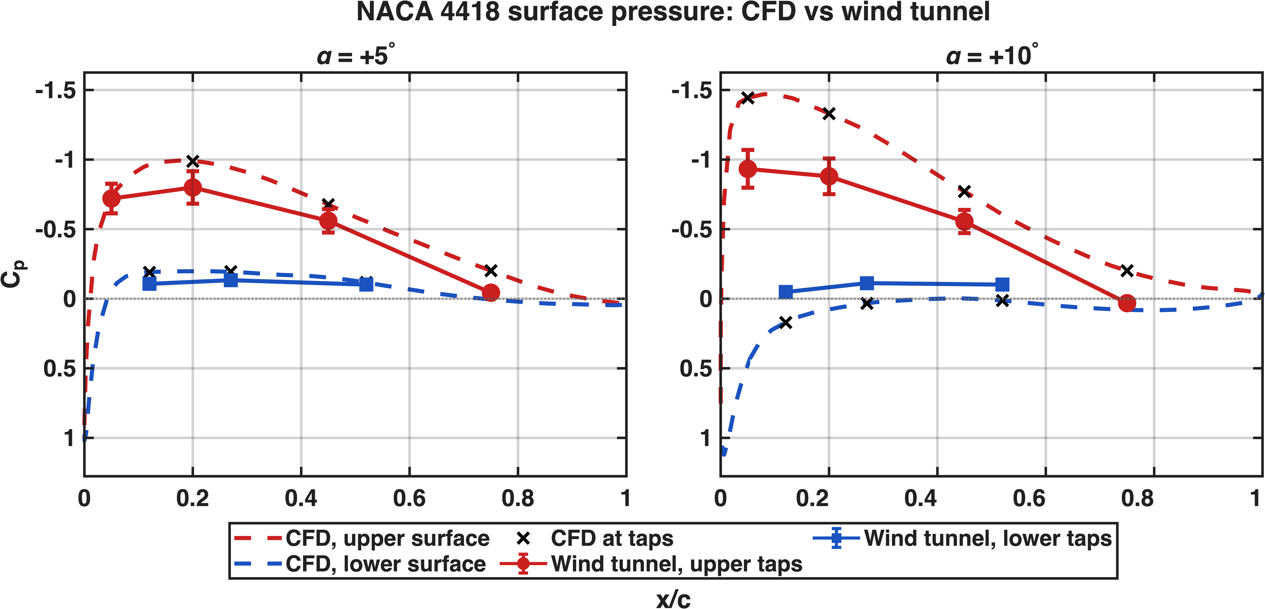
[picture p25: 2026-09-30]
[Codes] Wind Tunnel/# MATLAB Scripts/Poster Plots/poster_figures/Poster_NACA_Cp_5_10.png

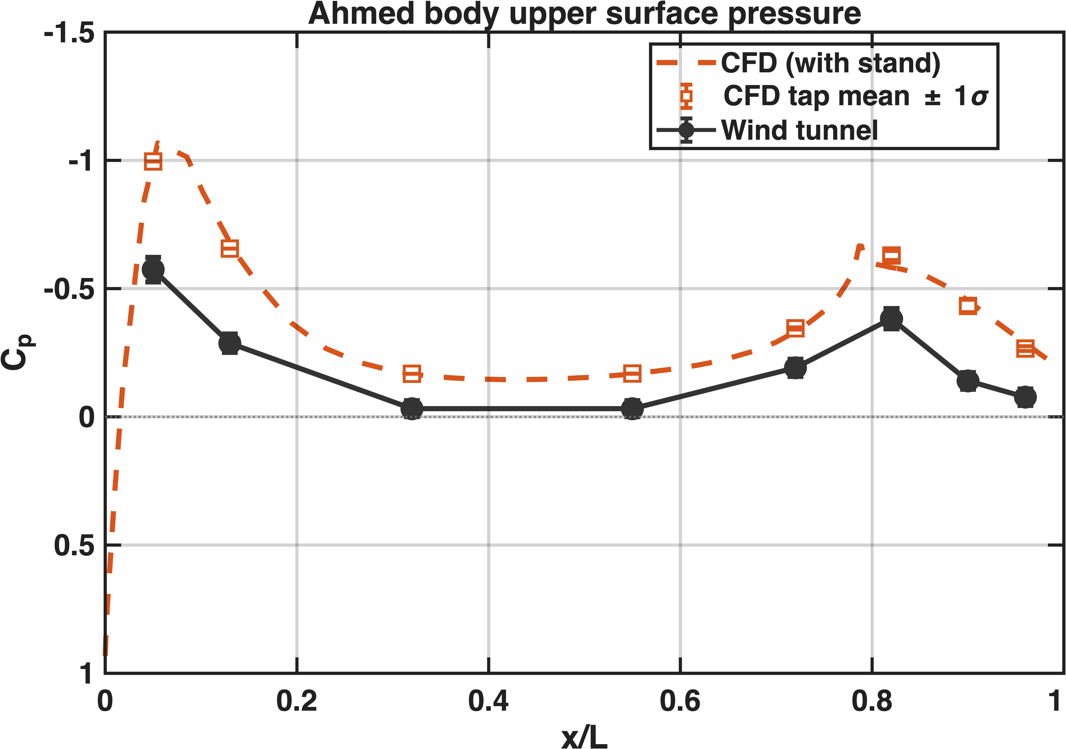
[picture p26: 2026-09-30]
[Codes] Wind Tunnel/# MATLAB Scripts/Poster Plots/poster_figures/Poster_Ahmed_Cp.png

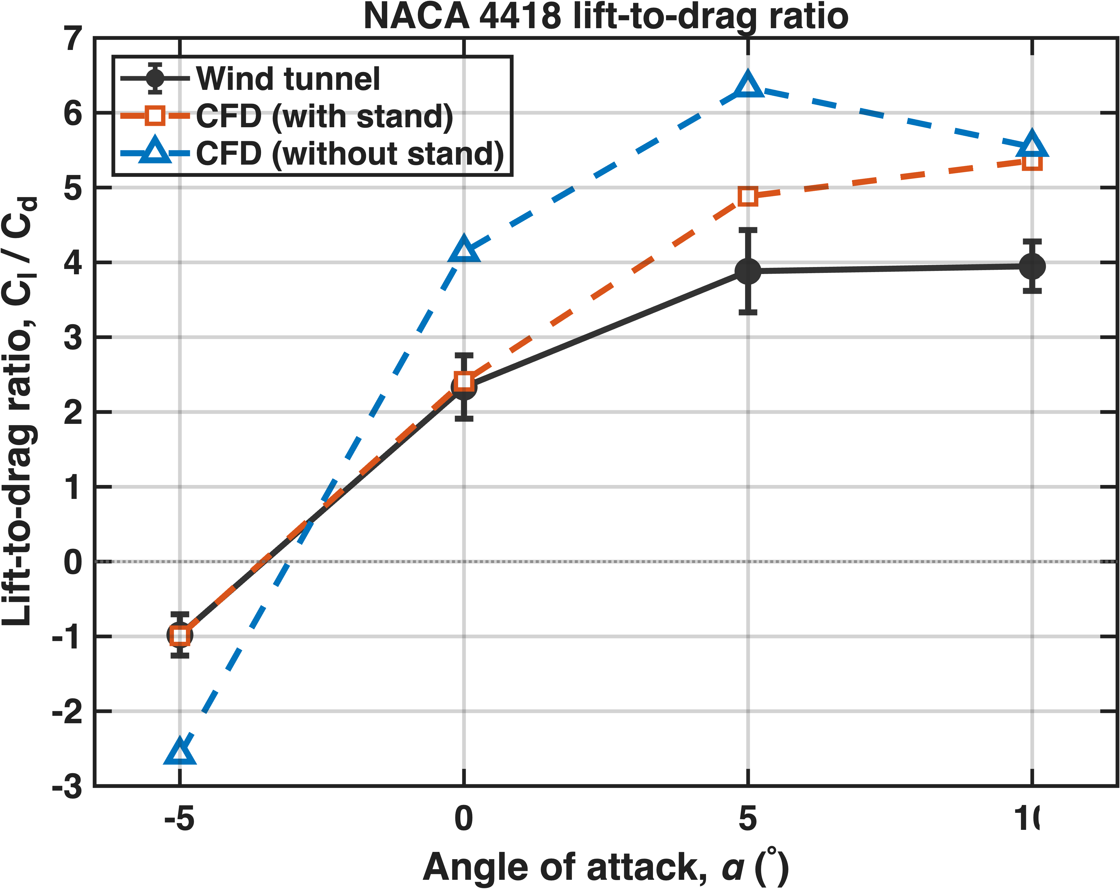
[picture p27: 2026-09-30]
[Codes] Wind Tunnel/# MATLAB Scripts/Poster Plots/poster_figures/Poster_NACA_LD.png

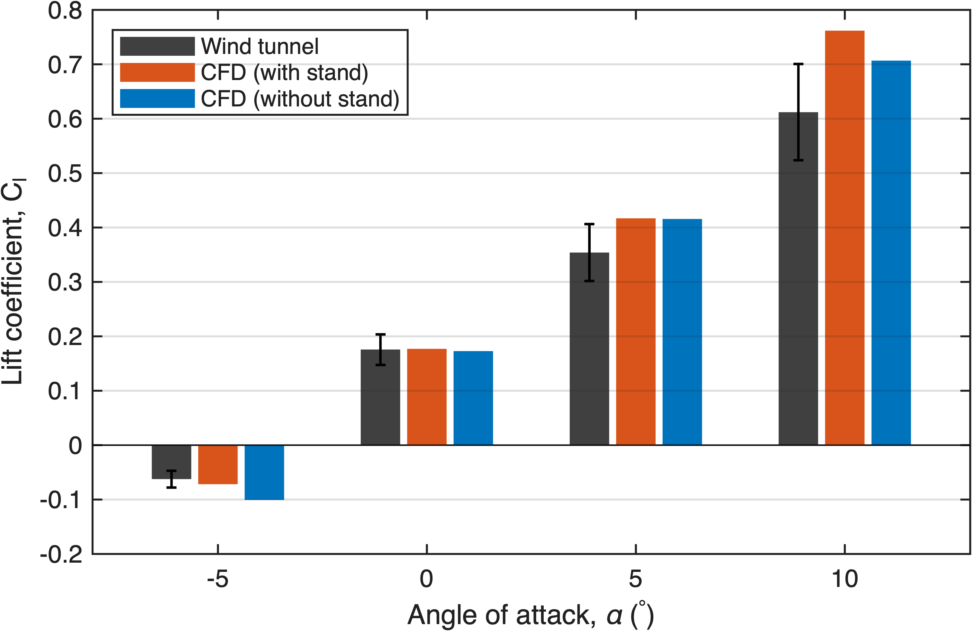
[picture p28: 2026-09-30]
[Codes] Wind Tunnel/# MATLAB Scripts/[NACA] CFD vs WT Plots/figures/NACA_Cl_WT_vs_CFD.png

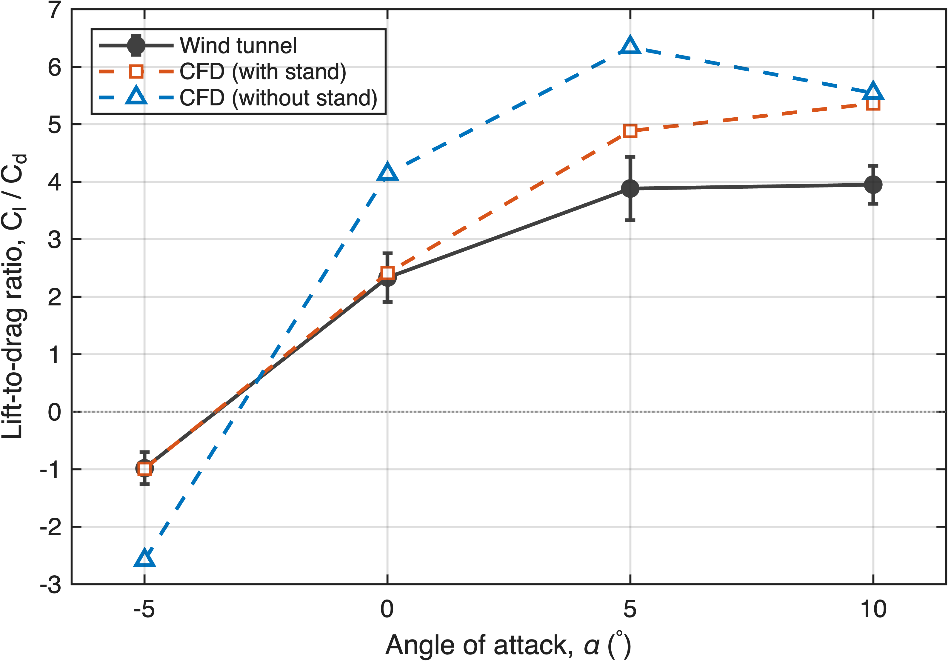
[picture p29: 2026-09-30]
[Codes] Wind Tunnel/# MATLAB Scripts/[NACA] CFD vs WT Plots/figures/NACA_LD_WT_vs_CFD.png

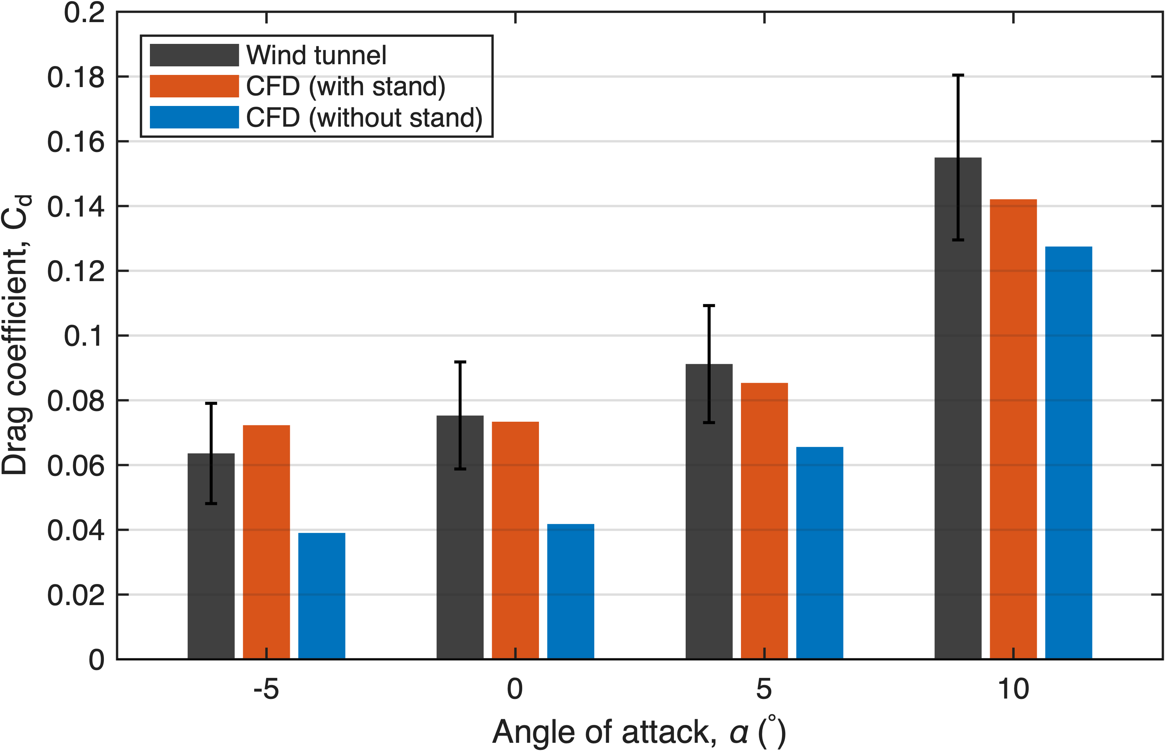
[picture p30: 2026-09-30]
[Codes] Wind Tunnel/# MATLAB Scripts/[NACA] CFD vs WT Plots/figures/NACA_Cd_WT_vs_CFD.png

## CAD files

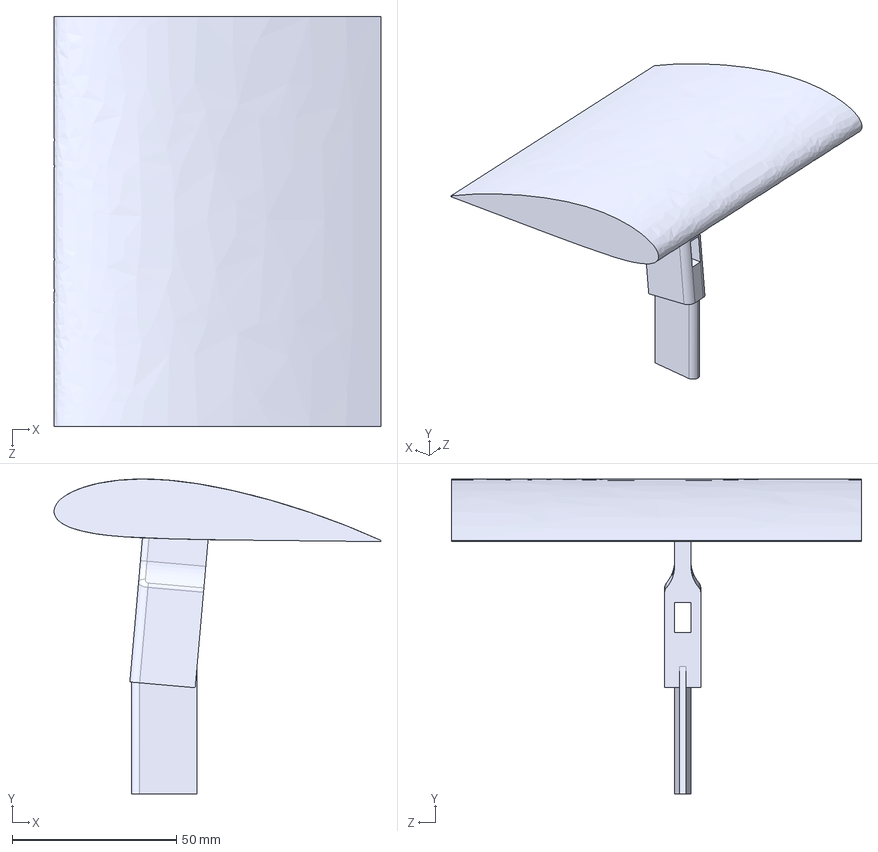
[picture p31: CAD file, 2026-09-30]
[CFD] Wind Tunnel/CFD WITH Stand/NACA4418 @ +5 deg AoA/CAD Model/NACA4418 Assembly +5 AoA.STEP
99.7 x 96.0 x 125.0 mm

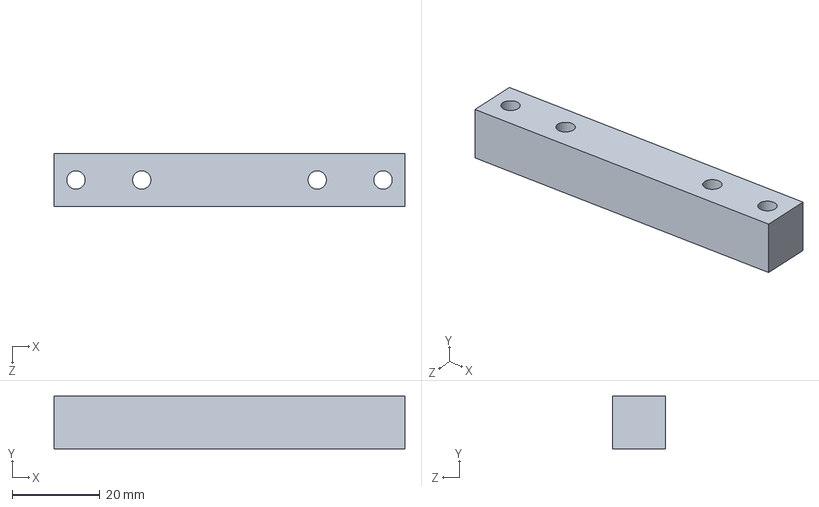
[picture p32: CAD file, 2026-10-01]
[CAD] Wind Tunnel/Models, Lever, Smoke Rake/Load Cell Lever/Load Cell.SLDPRT
80.0 x 12.0 x 12.0 mm

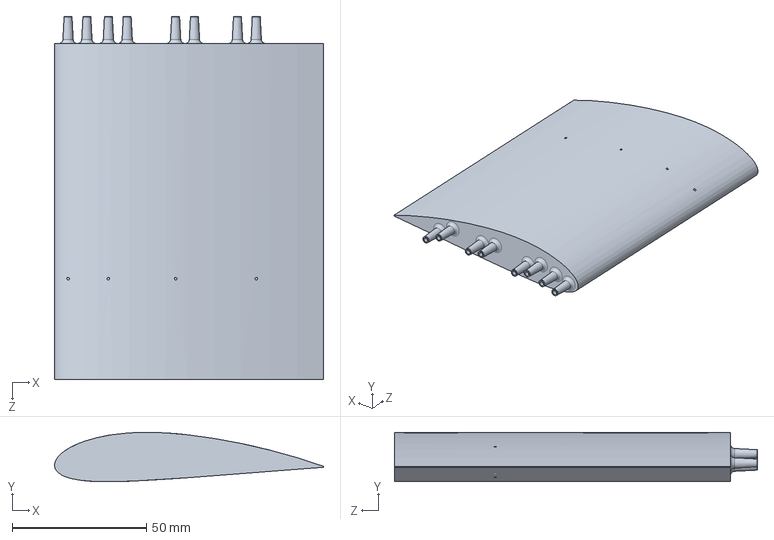
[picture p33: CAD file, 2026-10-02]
[CAD] Wind Tunnel/Models, Lever, Smoke Rake/NACA 4418 model.SLDPRT
100.0 x 18.4 x 135.0 mm

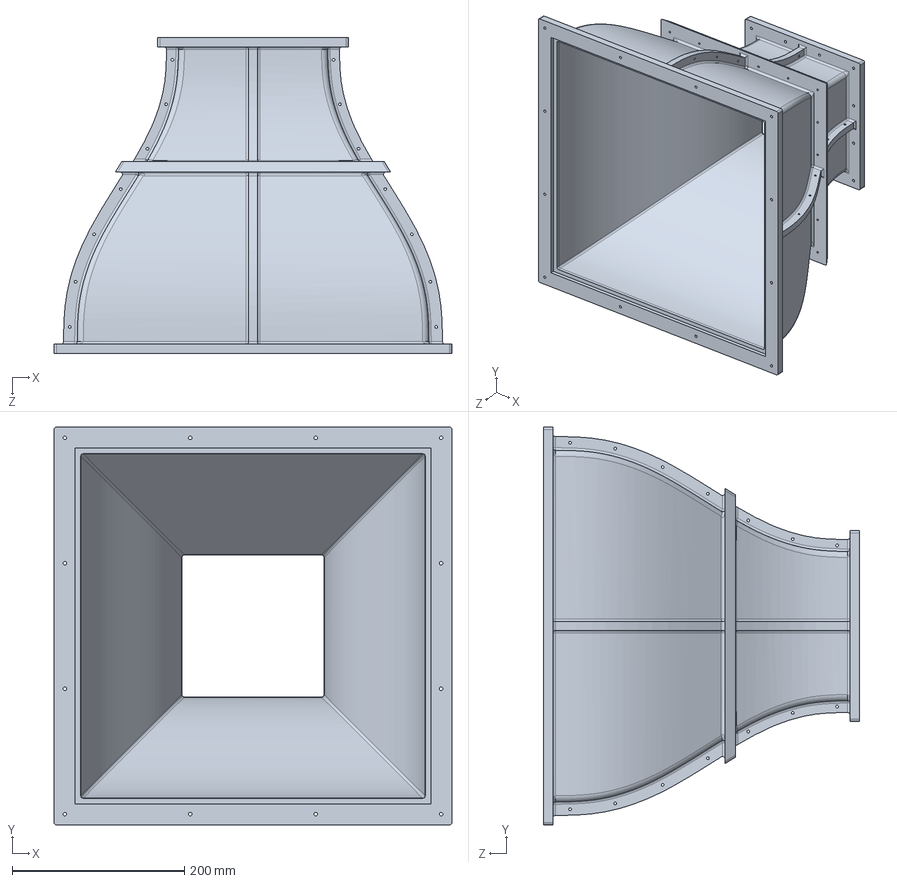
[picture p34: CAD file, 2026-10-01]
[CAD] Wind Tunnel/Tunnel Sections/Contraction cone.SLDPRT
462.0 x 462.0 x 367.2 mm

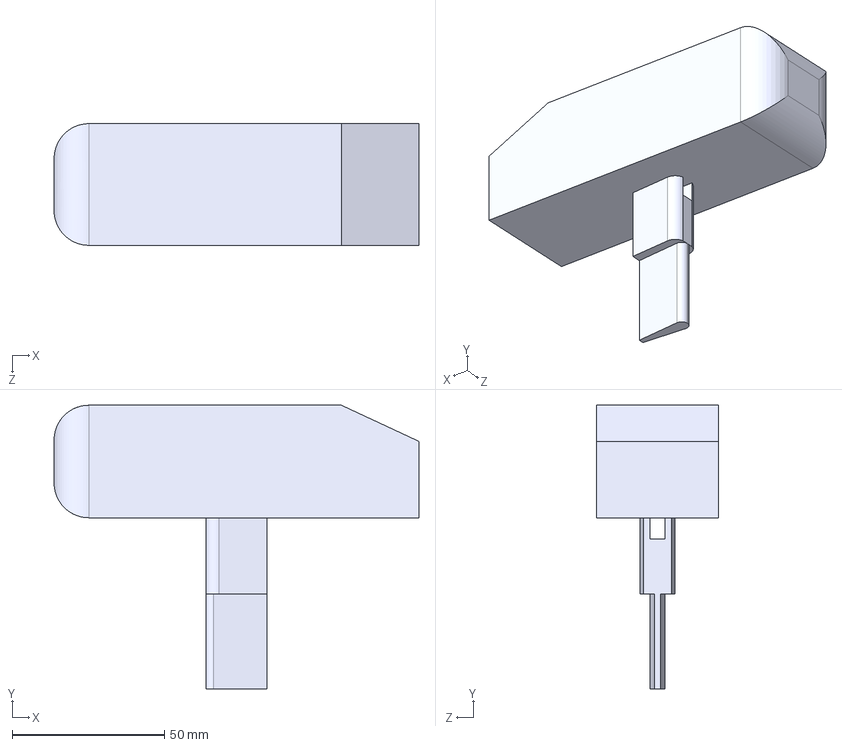
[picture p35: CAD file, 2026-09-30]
[CFD] Wind Tunnel/CFD WITH Stand/Ahmed Body/CAD Model/Ahmed Body with Stand.STEP
120.1 x 93.3 x 40.0 mm

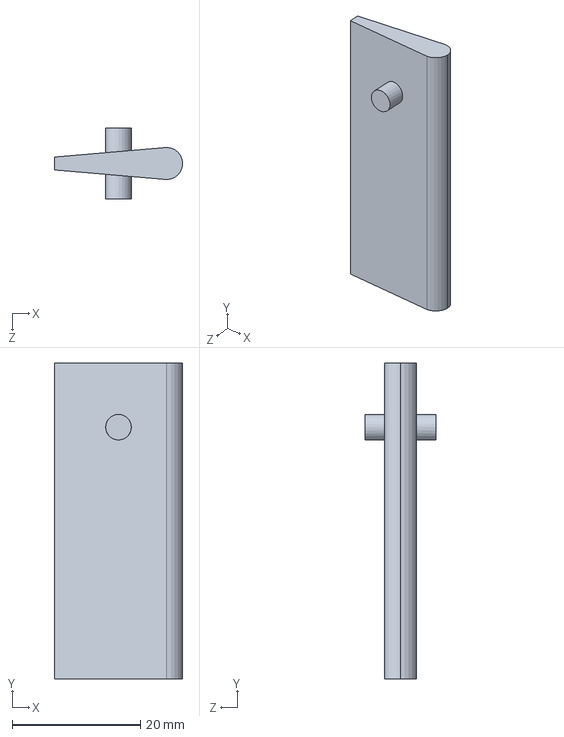
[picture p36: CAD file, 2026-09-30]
[CFD] Wind Tunnel/CFD WITH Stand/NACA4418 @ +10 deg AoA/CAD Model/Vertical Support Stand.SLDPRT
20.0 x 49.2 x 11.0 mm

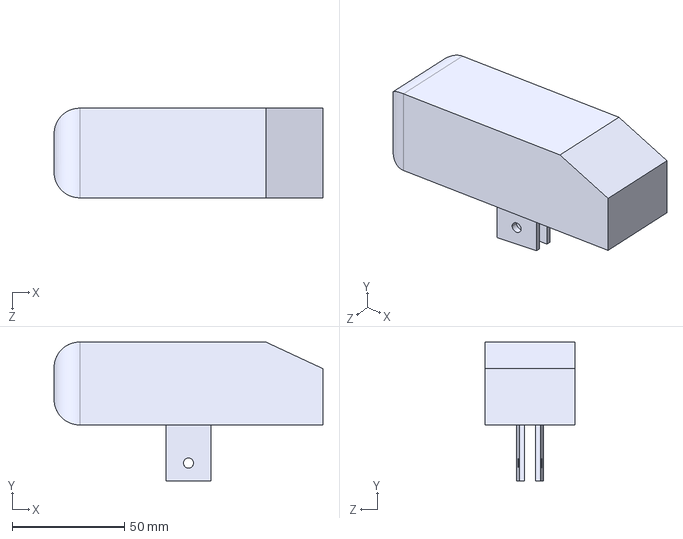
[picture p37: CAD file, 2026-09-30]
[CFD] Wind Tunnel/CFD Without Stand/Ahmed Body/Ahmed body Sim.STEP
120.1 x 62.0 x 40.0 mm

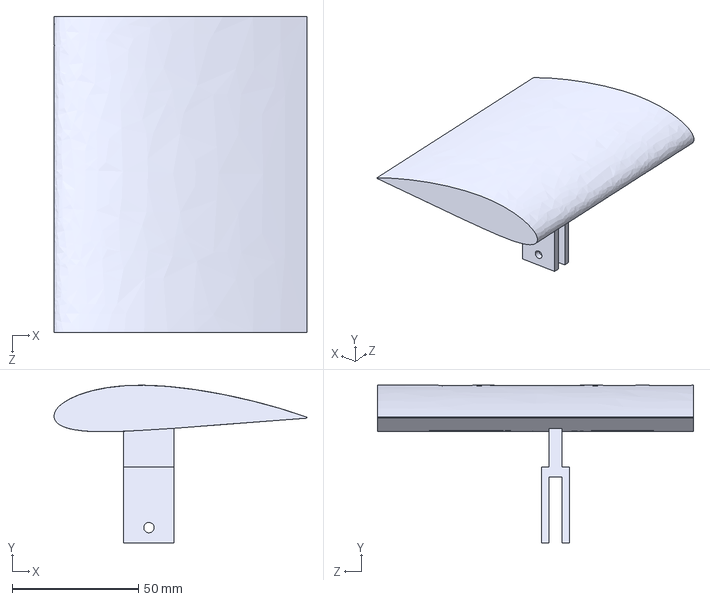
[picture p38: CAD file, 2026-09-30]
[CFD] Wind Tunnel/CFD Without Stand/NACA 4418 AoA=0/NACA 4418 v2.STEP
100.1 x 62.3 x 125.0 mm

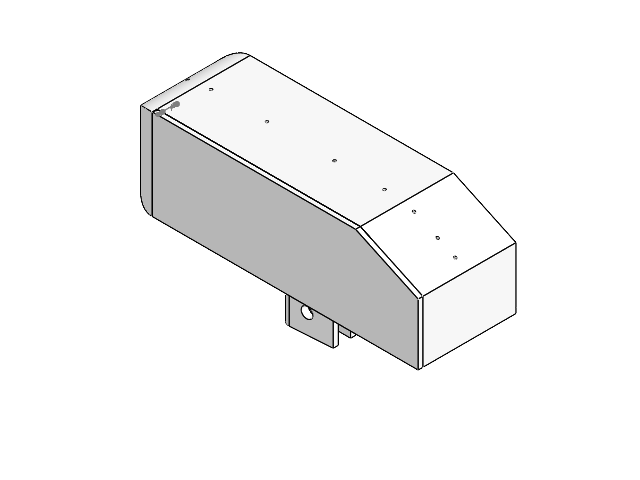
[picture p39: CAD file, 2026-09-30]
[CAD] Wind Tunnel/Models, Lever, Smoke Rake/Ahmed Body v2/Ahmed Assembly.SLDASM
Ahmed body v2
Ahmed side cover

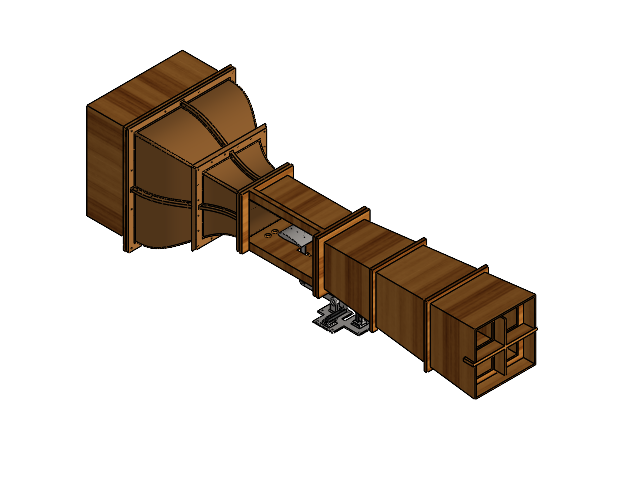
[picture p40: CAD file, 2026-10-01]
[CAD] Wind Tunnel/Wind Tunnel w NACA 4418.SLDASM
Test Section
Contraction cone
Settling chamber
Diffuser
Vertical stint
Lift lever
Drag lever
Load Cell x 2
Drag Load Cell Support
Lift Load Cell Support
Lever Base and Supports
NACA 4418 model

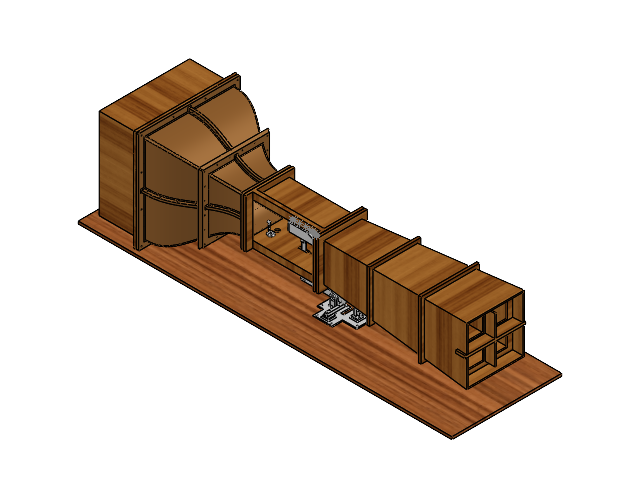
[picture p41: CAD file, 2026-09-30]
[CAD] Wind Tunnel/Wind Tunnel w Ahmed Body.SLDASM
Platform
Test Section
Contraction cone
Settling chamber
Diffuser
Vertical stint
Lift lever
Drag lever
Load Cell x 2
Lever Base and Supports
Pitot Stand
(Obsolete) Ahmed body

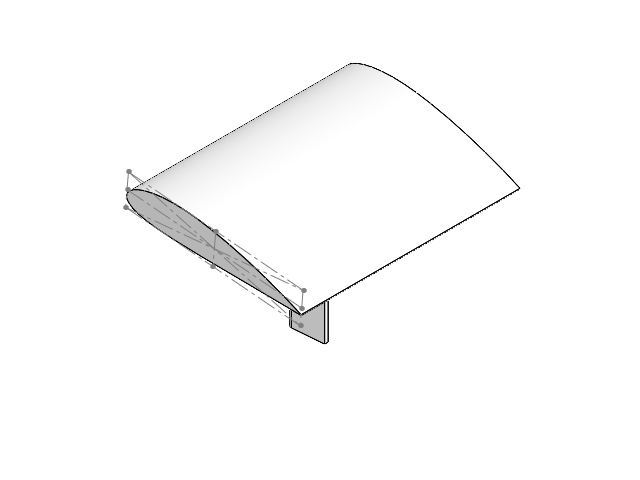
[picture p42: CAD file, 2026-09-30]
[CFD] Wind Tunnel/CFD WITH Stand/NACA4418 @ +5 deg AoA/CAD Model/NACA4418 Assembly.SLDASM
NACA4418
Vertical Support Stand

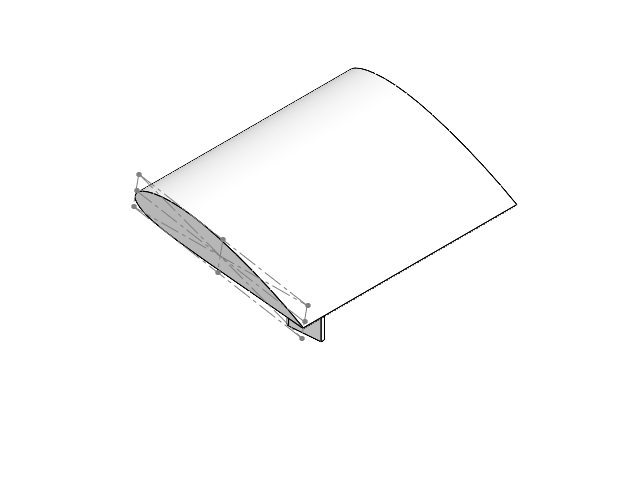
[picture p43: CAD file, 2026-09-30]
[CFD] Wind Tunnel/CFD WITH Stand/NACA4418 @ +10 deg AoA/CAD Model/NACA4418 Assembly.SLDASM
NACA4418
Vertical Support Stand

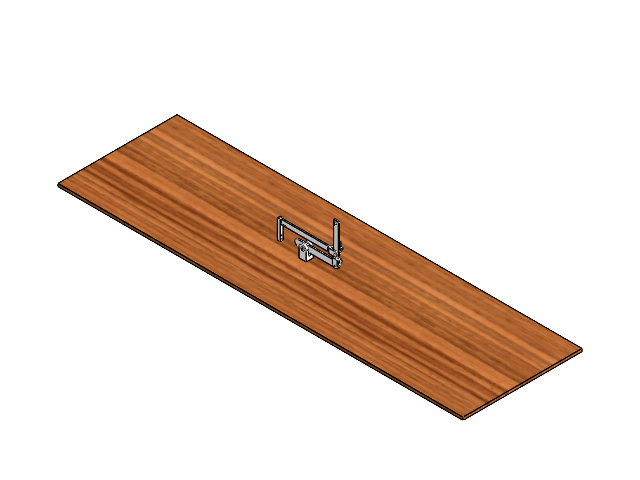
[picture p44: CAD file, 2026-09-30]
[CAD] Wind Tunnel/Models, Lever, Smoke Rake/Load Cell Lever/Lever system 2.SLDASM
Platform
Ball Bearing Demo x 4
lift lever
pin x 3
vertical stint
drag lever
Load Cell

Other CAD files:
[CFD] Wind Tunnel/CFD WITH Stand/NACA4418 @ -5 deg AoA/CAD Model/NACA4418 Assembly.STEP
[CAD] Wind Tunnel/2D CAD for Laser Cutting/Square Flanges for Settling Chamber and Diffuser.SLDPRT
[CFD] Wind Tunnel/CFD WITH Stand/NACA4418 @ 0 deg AoA/CAD Model/NACA4418 0 AoA.STEP
[CAD] Wind Tunnel/(Obsolete) Rotating Selector for Pressure Taps/Bottom plate.SLDPRT
[CAD] Wind Tunnel/(Obsolete) Rotating Selector for Pressure Taps/Manifold.SLDPRT
[CAD] Wind Tunnel/(Obsolete) Rotating Selector for Pressure Taps/Rotating Selector.SLDASM
[CAD] Wind Tunnel/(Obsolete) Rotating Selector for Pressure Taps/Stepper holder.SLDPRT
[CAD] Wind Tunnel/(Obsolete) Rotating Selector for Pressure Taps/Stepper.SLDPRT
[CAD] Wind Tunnel/(Obsolete) Rotating Selector for Pressure Taps/Top plate.SLDPRT
[CAD] Wind Tunnel/2D CAD for Laser Cutting/Major Plywood Panels.DXF
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

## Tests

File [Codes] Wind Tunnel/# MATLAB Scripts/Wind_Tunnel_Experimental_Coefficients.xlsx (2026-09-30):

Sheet: README
Wind Tunnel — experimental coefficients (bookkeeping)
Data sheets (row 1 = header, one record per row, no merged cells — read directly with readtable):
NACA_Forces : AoA_deg, Cl, Cd
NACA_Cp : AoA_deg, Cp_u_x05, Cp_u_x20, Cp_u_x45, Cp_u_x75, Cp_l_x12, Cp_l_x27, Cp_l_x52, Cp_l_x68
(u/l = upper/lower surface, xNN = tap at x/c = 0.NN)
Ahmed_Forces: Cd
Ahmed_Cp : x_L, Cp
Adding new test data: one row per AoA — add a row for a new angle, overwrite the row when re-testing an existing angle. No blank rows.
Reference values used to compute the coefficients (documentation only, not read by code):
Force retest (NACA −5°, 5°, 10°; Ahmed): freestream speed measured with pitot tubes during the run.
NACA 0° forces and NACA Cp (older tests): U∞ = 17.5 m/s assumed, ρ = 1.225 kg/m³, q∞ = 187.58 Pa
Ahmed Cp (older test): U∞ = 16 m/s, ρ = 1.225 kg/m³, q∞ = 156.8 Pa
NACA 4418: c = 100 mm, A_ref = 0.0125 m² (125 mm span)
Ahmed body (120×40×37 mm): L = 120 mm, A_ref = 0.00148 m² (frontal)
Cp = p/q∞, Cl = L/(q∞·A_ref), Cd = D/(q∞·A_ref)
Notes: drag includes the model stand; no blockage correction applied.

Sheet: NACA_Forces
AoA_deg | Cl | Cd
-5 | -0.0624 | 0.0636
0 | 0.1757 | 0.0753
5 | 0.3540 | 0.0912
10 | 0.6120 | 0.1550

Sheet: NACA_Cp
AoA_deg | Cp_u_x05 | Cp_u_x20 | Cp_u_x45 | Cp_u_x75 | Cp_l_x12 | Cp_l_x27 | Cp_l_x52 | Cp_l_x68
-5 | 0.2506 | -0.2932 | -0.3838 | -0.0906 | -0.6664 | -0.3519 | -0.1759 | -0.2132
0 | -0.2186 | -0.5651 | -0.4531 | -0.0640 | -0.2985 | -0.2026 | -0.1279 | -0.1813
5 | -0.7197 | -0.7997 | -0.5598 | -0.0426 | -0.1066 | -0.1333 | -0.1013 | -0.2506
10 | -0.9329 | -0.8796 | -0.5544 | 0.0320 | -0.0480 | -0.1120 | -0.1013 | -0.2506

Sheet: Ahmed_Forces
Cd
0.6714

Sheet: Ahmed_Cp
x_L | Cp
0.05 | -0.5740
0.13 | -0.2870
0.32 | -0.0319
0.55 | -0.0319
0.72 | -0.1913
0.82 | -0.3827
0.90 | -0.1403
0.96 | -0.0765

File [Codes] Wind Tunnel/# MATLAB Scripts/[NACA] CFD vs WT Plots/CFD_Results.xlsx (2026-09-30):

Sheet: README
NACA 4418 & Ahmed body — CFD results (Ansys Fluent, steady RANS k-ω SST, test-section digital twin)
Data sheets (row 1 = header, one record per row):
NACA_Forces : AoA_deg, Cl_stand, Cd_stand, Cl_nostand, Cd_nostand
Ahmed_Forces: Cd_stand, Cd_nostand
Ahmed_Cp : x_L, Cp_stand
(_stand = model + stand in CFD; _nostand = model only)
Reference values: NACA A_ref = 0.0125 m², U = 17.5 m/s; Ahmed A_ref = 0.00148 m² (stand: U = 16 m/s, no stand: U = 17.5 m/s); ρ = 1.225 kg/m³
Notes:
NACA 10° no stand: steady solution oscillated — values are means over the last 4 whole cycles.
NACA 10° with stand: refined mesh (4 wake levels on NACA, 2 on stand, edge refinements).
NACA −5° no stand: Cl recomputed from Fl = −0.236 N (log listed −0.1).
Ahmed no stand: Cd recomputed from D = 0.123 N at 17.5 m/s (log listed 0.44). Standless Ahmed Cp superseded by the with-stand run, so not stored.
Ahmed with stand: means over the logged iterations (Cd = 0.616 ± 0.004).
NACA surface Cp is read directly from the tap-plane .crash exports by the MATLAB script, not stored here.

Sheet: NACA_Forces
AoA_deg | Cl_stand | Cd_stand | Cl_nostand | Cd_nostand
-5 | -0.07173 | 0.07231 | -0.1007 | 0.03903
0 | 0.177 | 0.0734 | 0.1729 | 0.04178
5 | 0.4169 | 0.08536 | 0.4157 | 0.06558
10 | 0.7618 | 0.1421 | 0.7067 | 0.1275

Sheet: Ahmed_Forces
Cd_stand | Cd_nostand
0.6159 | 0.4431

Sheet: Ahmed_Cp
x_L | Cp_stand
0.05 | -0.9958
0.13 | -0.6561
0.32 | -0.1677
0.55 | -0.1688
0.72 | -0.345
0.82 | -0.6288
0.90 | -0.432
0.96 | -0.2666

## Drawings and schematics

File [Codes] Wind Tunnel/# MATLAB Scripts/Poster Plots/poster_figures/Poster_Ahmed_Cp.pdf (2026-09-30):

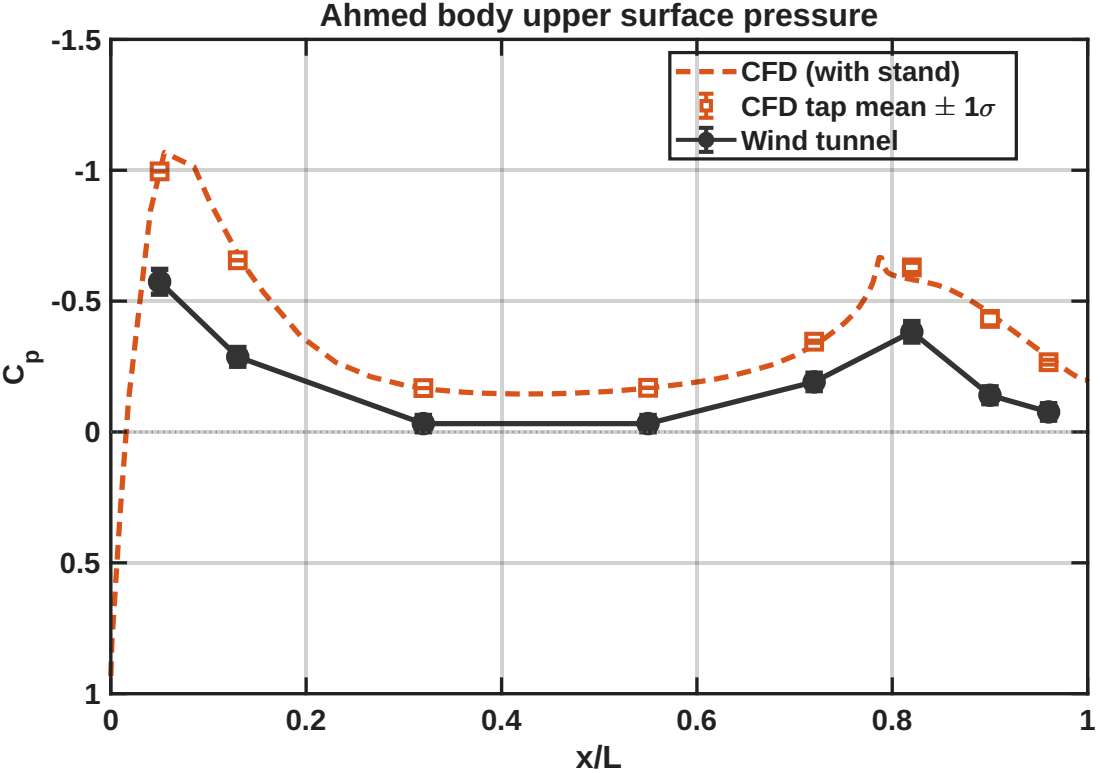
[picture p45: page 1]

Ahmed body upper surface pressure

CFD (with stand)
CFD tap mean ' 1<
Wind tunnel

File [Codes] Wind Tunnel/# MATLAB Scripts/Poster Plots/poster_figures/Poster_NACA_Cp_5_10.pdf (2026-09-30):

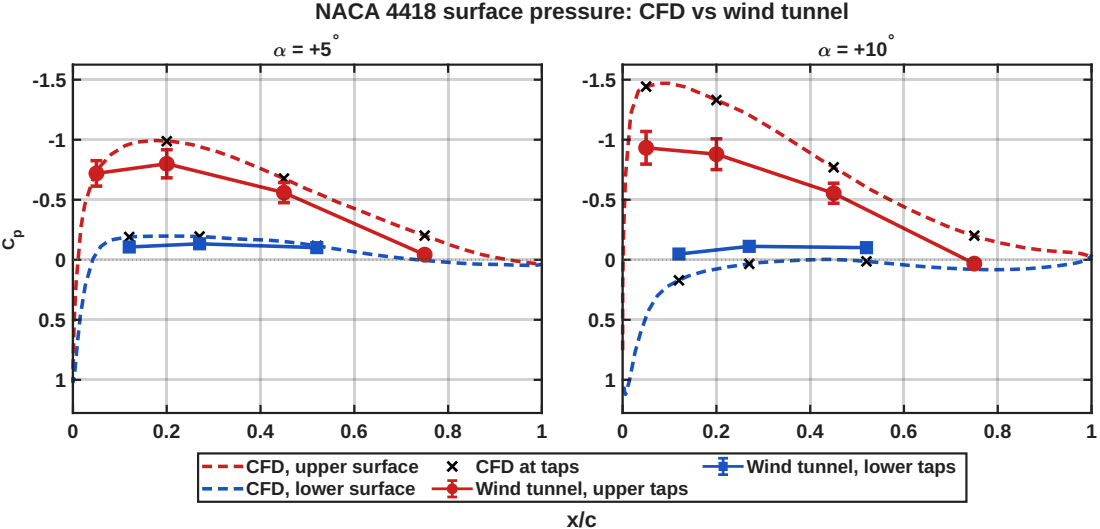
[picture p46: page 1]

NACA 4418 surface pressure: CFD vs wind tunnel

CFD, upper surface
CFD, lower surface

CFD at taps
Wind tunnel, upper taps

Wind tunnel, lower taps

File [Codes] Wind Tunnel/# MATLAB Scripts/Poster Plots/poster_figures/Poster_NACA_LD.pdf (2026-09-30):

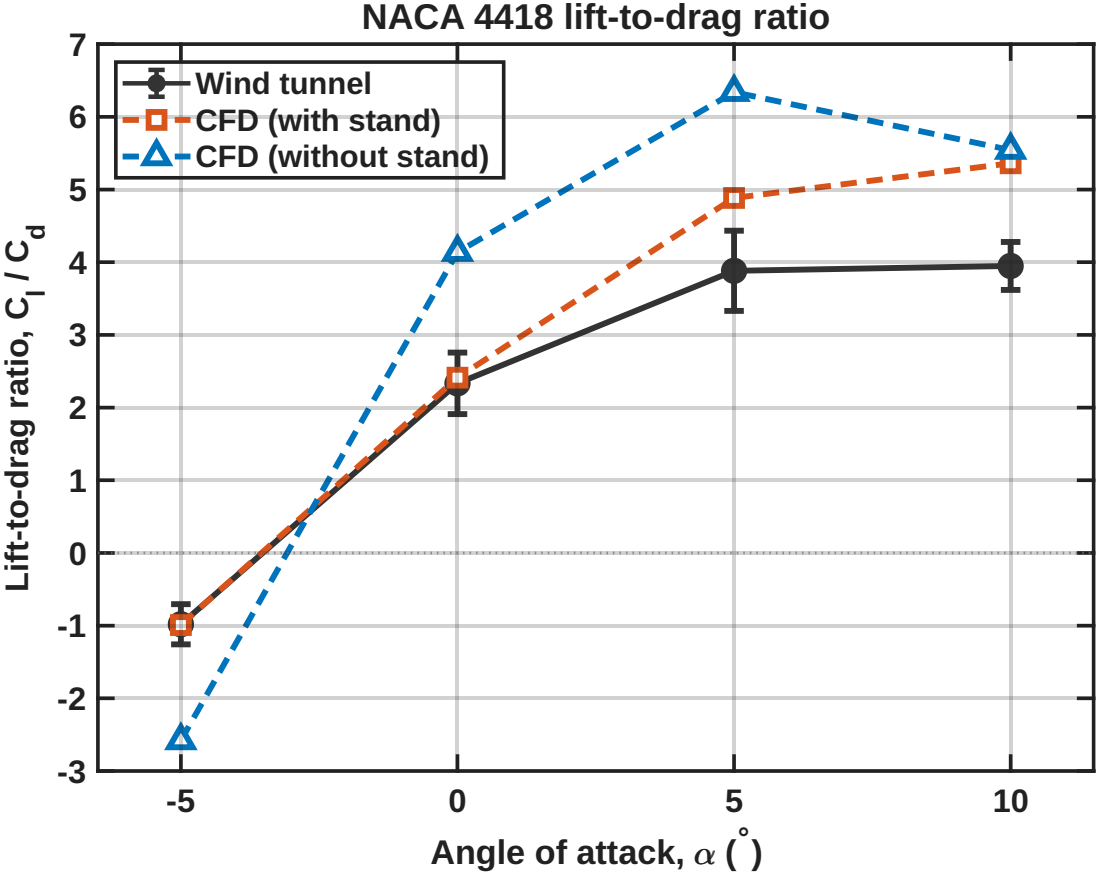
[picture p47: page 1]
g ratio, Cl

NACA 4418 lift-to-drag ratio

Wind tunnel CFD (with stand)

CFD (without stand)

Lift-to-dra

Angle of attack, , (

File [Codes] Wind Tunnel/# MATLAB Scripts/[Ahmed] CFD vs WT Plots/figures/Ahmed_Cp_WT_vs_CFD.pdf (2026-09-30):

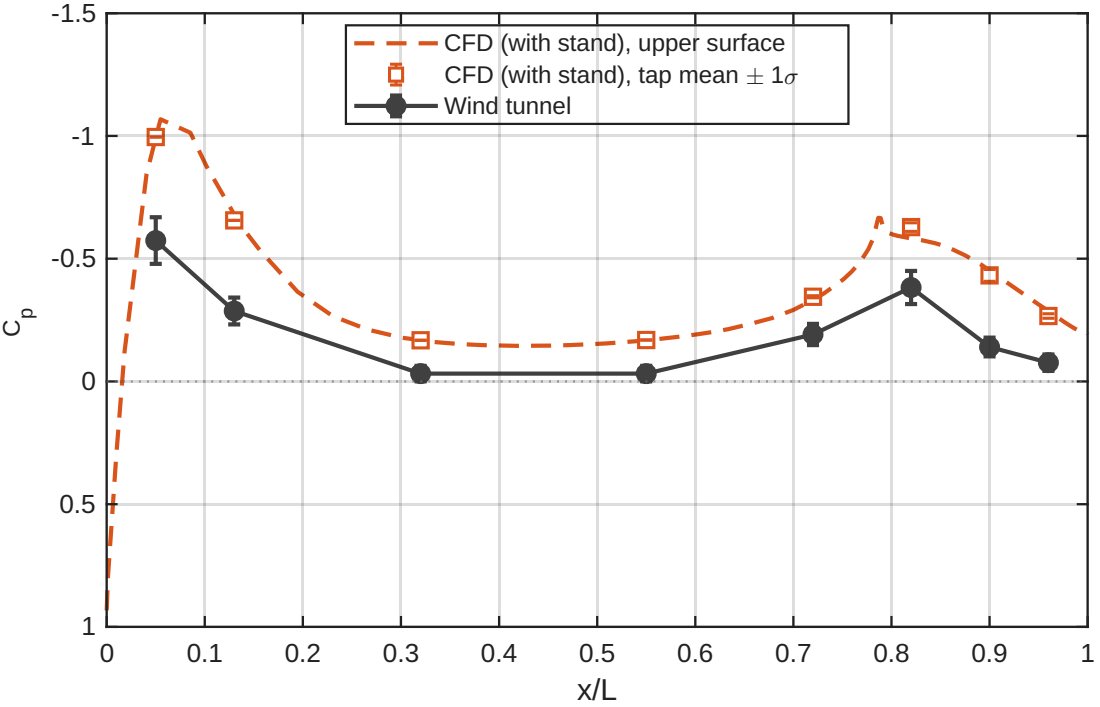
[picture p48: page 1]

CFD (with stand), upper surface
CFD (with stand), tap mean ' 1<
Wind tunnel

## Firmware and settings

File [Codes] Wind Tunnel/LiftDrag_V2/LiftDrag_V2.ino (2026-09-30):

#include <HX711.h>
#include <EEPROM.h>
#include <math.h>

// ========== PIN DEFINITIONS ==========
const int LIFT_DOUT = 2;
const int LIFT_SCK  = 3;
const int DRAG_DOUT = 6;
const int DRAG_SCK  = 7;
const int PITOT_PIN = A3;   // MPXV7002DP on the Pitot-static tube (same pin as pressure_readings.ino)

HX711 scaleLift;
HX711 scaleDrag;

// ========== PITOT / FLOW CONSTANTS ==========
const float V_REF       = 4.93;                // measured 5 V rail
const float AIR_DENSITY = 1.164;               // kg/m^3 at 30 C
const float SENSITIVITY = 1.0 * (V_REF / 5.0); // V per kPa (MPXV7002DP is ratiometric)
const float G_ACC       = 9.788;               // m/s^2, local gravity (Dhaka), grams -> newtons
const float Q_MIN_VEL   = 0.5;                 // Pa: below this, velocity is reported as 0
const float Q_MIN_COEF  = 5.0;                 // Pa (~2.9 m/s): below this, CdA/ClA are reported as nan

// Lever amplification. Leave at 1.0 if the calibration masses were hung at the
// model/sting (the calibration slope then already contains the lever ratio).
// If the masses were hung directly on the load cells, set these to 4.0 / 4.5.
const float LIFT_LEVER = 1.0;
const float DRAG_LEVER = 1.0;

float offsetVoltage = 0.0;   // Pitot zero-pressure baseline (fan OFF)

// ========== CALIBRATION PARAMETERS ==========
float slopeLift = 0.0, interceptLift = 0.0;
float slopeDrag = 0.0, interceptDrag = 0.0;
bool calibrated = false;

// EEPROM storage – only slopes are saved
struct CalData {
  float slopeLift;
  float slopeDrag;
};
CalData calData;

// ========== CALIBRATION DATA COLLECTION ==========
const int MAX_POINTS = 20;
int pointCount = 0;

// ========== STREAMING ACCUMULATORS ==========
// The HX711s run at 10 samples/s, so each one is "ready" only every ~100 ms.
// Instead of blocking while we wait for them, the Pitot ADC is sampled every
// 1 ms in the meantime. One output line = HX_SAMPLES readings from each load
// cell plus every Pitot sample taken over the same time window (~500 samples).
const int HX_SAMPLES = 5;                    // ~2 lines per second at 10 SPS
const unsigned long ADC_INTERVAL_US = 1000;  // Pitot sampling period

long adcSum = 0;      unsigned long adcCount = 0;
long liftRawSum = 0;  int liftCount = 0;
long dragRawSum = 0;  int dragCount = 0;
unsigned long lastAdcMicros = 0;

void resetAccumulators() {
  adcSum = 0;     adcCount = 0;
  liftRawSum = 0; liftCount = 0;
  dragRawSum = 0; dragCount = 0;
}

// ========== HELPER: READ AVERAGE RAW VALUE ==========
float readAverage(HX711 &scale, int samples = 10, int delayMs = 10) {
  long sum = 0;
  for (int i = 0; i < samples; i++) {
    while (!scale.is_ready()) delay(5);
    sum += scale.get_units(1);   // raw value (scale factor = 1)
    delay(delayMs);
  }
  return (float)sum / samples;
}

// ========== HELPER: CLEAR SERIAL BUFFER ==========
void clearSerial() {
  delay(50);
  while (Serial.available()) Serial.read();
}

void waitForKey() {
  while (!Serial.available()) delay(10);
  clearSerial();
}

// ========== OUTPUT FORMATTING ==========
// Column widths for the CSV table (padding spaces are harmless in CSV)
const int W_U = 7, W_D = 8, W_L = 8, W_CDA = 10, W_CLA = 10;

void printPadded(const char* s, int width) {
  for (int i = strlen(s); i < width; i++) Serial.print(' ');
  Serial.print(s);
}

// Print x to 3 significant figures, right-aligned in a field of `width` chars
// (e.g. 17.4, 250, 30.0, 0.00167, -0.0556); NaN prints as "nan"
void printSig3(float x, int width) {
  if (isnan(x)) { printPadded("nan", width); return; }
  char buf[20];
  int decimals = 2;
  float a = fabs(x);
  if (a > 0) {
    int mag = (int)floor(log10(a));
    decimals = 2 - mag;
    if (decimals < 0) decimals = 0;
    // rounding can push it up a decade (9.996 -> 10.0): drop one decimal
    float p = pow(10, decimals);
    if (decimals > 0 && round(a * p) / p >= pow(10, mag + 1)) decimals--;
  }
  dtostrf(x, width, decimals, buf);   // AVR has no %f in sprintf
  Serial.print(buf);
}

void printHeader() {
  printPadded("U_m/s",  W_U);   Serial.print(", ");
  printPadded("Drag_g", W_D);   Serial.print(", ");
  printPadded("Lift_g", W_L);   Serial.print(", ");
  printPadded("CdA_m2", W_CDA); Serial.print(", ");
  printPadded("ClA_m2", W_CLA); Serial.println();
}

// ========== TARE FUNCTIONS ==========
void doLoadCellTare() {
  float rawTareLift = 0, rawTareDrag = 0;
  for (int i = 0; i < 10; i++) {
    rawTareLift += readAverage(scaleLift, 5, 10);
    rawTareDrag += readAverage(scaleDrag, 5, 10);
  }
  rawTareLift /= 10.0;
  rawTareDrag /= 10.0;

  // Intercept = -slope * rawTare  => mass = 0 when raw = rawTare
  if (fabs(slopeLift) > 1e-6) interceptLift = -slopeLift * rawTareLift;
  else interceptLift = 0;
  if (fabs(slopeDrag) > 1e-6) interceptDrag = -slopeDrag * rawTareDrag;
  else interceptDrag = 0;

  Serial.println("Lift and Drag zeroed.");
}

void doPitotTare() {
  // Same mandatory zero-pressure tare as pressure_readings.ino (fan OFF)
  long sum = 0;
  for (int i = 0; i < 100; i++) {
    sum += analogRead(PITOT_PIN);
    delay(10);
  }
  offsetVoltage = (sum / 100.0) * V_REF / 1023.0;

  Serial.print("Pitot baseline zero-voltage: ");
  printSig3(offsetVoltage, 0);
  Serial.println(" V");
}

// Load cells only (used inside the calibration routine)
void tareLoadCells() {
  Serial.println("\nRemove any load from both cells, then press any key...");
  waitForKey();
  doLoadCellTare();
  Serial.println("✅ Tare complete.");
}

// Load cells + Pitot (startup and the 't' command)
void tareAll() {
  Serial.println("\nFan OFF and no load on the model, then press any key to tare...");
  waitForKey();
  doLoadCellTare();
  doPitotTare();
  Serial.println("✅ Tare complete (load cells + Pitot).");
}

// ========== INDIVIDUAL CALIBRATION ROUTINE ==========
void runCalibration(char sensorType) {
  String sensorName = (sensorType == 'l') ? "LIFT" : "DRAG";
  HX711* activeScale = (sensorType == 'l') ? &scaleLift : &scaleDrag;

  float rawPoints[MAX_POINTS];
  float massPoints[MAX_POINTS];

  Serial.print("\n--- START CALIBRATION: ");
  Serial.print(sensorName);
  Serial.println(" ---");
  Serial.print("Apply known mass to ");
  Serial.print(sensorName);
  Serial.println(" (or type 'x' to finish).");
  pointCount = 0;

  while (pointCount < MAX_POINTS) {
    Serial.print("\nEnter mass in grams (or 'x' to finish): ");
    while (!Serial.available()) delay(10);
    String input = Serial.readStringUntil('\n');
    input.trim();
    clearSerial();

    if (input.equalsIgnoreCase("x")) break;

    float mass = input.toFloat();
    if (mass < 0) {
      Serial.println("Mass must be >= 0.");
      continue;
    }

    // Read only the active scale
    float rawVal = readAverage(*activeScale, 10, 10);

    rawPoints[pointCount] = rawVal;
    massPoints[pointCount] = mass;
    pointCount++;

    Serial.print("Recorded: "); Serial.print(mass); Serial.println(" g");
    Serial.print(sensorName); Serial.print(" raw = "); Serial.println(rawVal);
  }

  if (pointCount < 2) {
    Serial.println("Not enough points. Aborting calibration.");
    return;
  }

  // ---- Least-squares fit ----
  float sumX = 0, sumY = 0, sumXY = 0, sumX2 = 0;
  for (int i = 0; i < pointCount; i++) {
    float x = rawPoints[i];
    float y = massPoints[i];
    sumX += x;
    sumY += y;
    sumXY += x * y;
    sumX2 += x * x;
  }

  float denom = pointCount * sumX2 - sumX * sumX;
  float calculatedSlope = 0.0;
  float calculatedIntercept = 0.0;

  if (fabs(denom) > 1e-6) {
    calculatedSlope = (pointCount * sumXY - sumX * sumY) / denom;
    calculatedIntercept = (sumY - calculatedSlope * sumX) / pointCount;

    if (sensorType == 'l') {
      slopeLift = calculatedSlope;
      interceptLift = calculatedIntercept;
    } else {
      slopeDrag = calculatedSlope;
      interceptDrag = calculatedIntercept;
    }
  } else {
    Serial.println("Calibration failed (denominator zero).");
    return;
  }

  // ---- Display results ----
  Serial.println("\n--- CALIBRATION RESULTS ---");
  Serial.print(sensorName); Serial.print(": slope = "); Serial.print(calculatedSlope, 6);
  Serial.print(", intercept = "); Serial.println(calculatedIntercept, 6);

  // ---- Verification (optional) ----
  Serial.print("\nApply a known weight to "); Serial.print(sensorName); Serial.println(" and type its mass to verify.");
  Serial.println("Type 's' to save and exit, 't' to tare first, or 'r' to redo.");

  while (true) {
    while (!Serial.available()) delay(10);
    String cmd = Serial.readStringUntil('\n');
    cmd.trim();
    clearSerial();

    if (cmd.equalsIgnoreCase("s")) {
      calData.slopeLift = slopeLift;
      calData.slopeDrag = slopeDrag;
      EEPROM.put(0, calData);
      calibrated = true;
      Serial.println("✅ Calibration saved to EEPROM.");
      break;
    } else if (cmd.equalsIgnoreCase("t")) {
      tareLoadCells();
      Serial.println("Tared. Continue verification or type 's' to save.");
    } else if (cmd.equalsIgnoreCase("r")) {
      Serial.println("Aborting save. Restarting calibration loop...");
      return;
    } else {
      float testMass = cmd.toFloat();
      if (testMass > 0) {
        float rawTest = readAverage(*activeScale, 10, 10);
        // use the live intercept so a 't' tare during verification is respected
        float liveIntercept = (sensorType == 'l') ? interceptLift : interceptDrag;
        float computed = calculatedSlope * rawTest + liveIntercept;
        Serial.print(sensorName); Serial.print(" reads: "); Serial.print(computed, 3); Serial.print(" g  (error = ");
        Serial.print(computed - testMass, 3); Serial.println(" g)");
      } else {
        Serial.println("Enter a mass to test, 's' to save, 't' to tare, or 'r' to redo.");
      }
    }
  }
}

// ========== CONTINUOUS MEASUREMENT (non-blocking) ==========
void streamMeasurements() {
  // 1. Pitot: sample the ADC every ADC_INTERVAL_US while waiting on the HX711s
  unsigned long now = micros();
  if (now - lastAdcMicros >= ADC_INTERVAL_US) {
    lastAdcMicros = now;
    adcSum += analogRead(PITOT_PIN);
    adcCount++;
  }

  // 2. Load cells: grab a reading only when a new conversion is ready
  if (liftCount < HX_SAMPLES && scaleLift.is_ready()) {
    liftRawSum += scaleLift.read();
    liftCount++;
  }
  if (dragCount < HX_SAMPLES && scaleDrag.is_ready()) {
    dragRawSum += scaleDrag.read();
    dragCount++;
  }

  // 3. Window complete -> compute and print one line
  if (liftCount < HX_SAMPLES || dragCount < HX_SAMPLES || adcCount == 0) return;

  // Forces (grams, then newtons)
  float rawL = (float)liftRawSum / liftCount;
  float rawD = (float)dragRawSum / dragCount;
  float lift_g = (slopeLift * rawL + interceptLift) / LIFT_LEVER;
  float drag_g = (slopeDrag * rawD + interceptDrag) / DRAG_LEVER;
  float lift_N = lift_g * 1e-3 * G_ACC;
  float drag_N = drag_g * 1e-3 * G_ACC;

  // Pitot -> dynamic pressure -> velocity (same method as pressure_readings.ino)
  float V_out    = ((float)adcSum / adcCount) * V_REF / 1023.0;
  float deltaV   = V_out - offsetVoltage;
  float q_Pa     = fabs(deltaV / SENSITIVITY * 1000.0);
  float velocity = 0.0;
  if (q_Pa > Q_MIN_VEL) velocity = sqrt((2.0 * q_Pa) / AIR_DENSITY);

  // Force coefficients times reference area [m^2]:  CxA = F / (0.5 * rho * U^2)
  // (0.5*rho*U^2 is just q_Pa again, so the assumed density cancels out here;
  //  it only affects the printed velocity.)
  float q_inf = 0.5 * AIR_DENSITY * velocity * velocity;
  float CdA = NAN, ClA = NAN;
  if (q_Pa > Q_MIN_COEF) {
    CdA = drag_N / q_inf;
    ClA = lift_N / q_inf;
  }

  // Output: velocity, drag, lift, Cd*A, Cl*A
  printSig3(velocity, W_U);  Serial.print(", ");
  printSig3(drag_g,   W_D);  Serial.print(", ");
  printSig3(lift_g,   W_L);  Serial.print(", ");
  printSig3(CdA,      W_CDA); Serial.print(", ");
  printSig3(ClA,      W_CLA); Serial.println();

  resetAccumulators();
}

// ========== SETUP ==========
void setup() {
  Serial.begin(9600);
  while (!Serial) ;
  Serial.setTimeout(50);

  scaleLift.begin(LIFT_DOUT, LIFT_SCK);
  scaleDrag.begin(DRAG_DOUT, DRAG_SCK);

  Serial.println("\n=== DUAL LOAD CELL + PITOT SYSTEM ===");

  // ---- Load saved slopes (blank EEPROM reads back as NaN, so reject that) ----
  EEPROM.get(0, calData);
  bool validCal = !isnan(calData.slopeLift) && !isnan(calData.slopeDrag) &&
                  (calData.slopeLift != 0.0 || calData.slopeDrag != 0.0);
  if (validCal) {
    slopeLift = calData.slopeLift;
    slopeDrag = calData.slopeDrag;
    calibrated = true;
    Serial.println("Previous calibration found in memory.");
  } else {
    Serial.println("No saved calibration. Use 'cl' or 'cd' to calibrate.");
  }

  // ---- Always perform a tare at startup (fan OFF) ----
  Serial.println("Performing initial tare...");
  tareAll();

  // ---- Menu ----
  Serial.println("\nCommands:");
  Serial.println("  t   - tare load cells + Pitot (fan OFF, no load)");
  Serial.println("  cl  - run calibration for LIFT");
  Serial.println("  cd  - run calibration for DRAG");
  Serial.println("  s   - save current slopes to EEPROM");
  Serial.println("  p   - print current calibration parameters");
  Serial.println("\nReady. Turn the fan on whenever you like.");
  printHeader();

  resetAccumulators();
  lastAdcMicros = micros();
}

// ========== MAIN LOOP ==========
void loop() {
  // Check for serial commands
  if (Serial.available()) {
    String cmd = Serial.readStringUntil('\n');
    cmd.trim();
    clearSerial();

    if (cmd.equalsIgnoreCase("t")) {
      tareAll();
    }
    else if (cmd.equalsIgnoreCase("cl")) {
      runCalibration('l');
    }
    else if (cmd.equalsIgnoreCase("cd")) {
      runCalibration('d');
    }
    else if (cmd.equalsIgnoreCase("s")) {
      calData.slopeLift = slopeLift;
      calData.slopeDrag = slopeDrag;
      EEPROM.put(0, calData);
      Serial.println("✅ Both slopes saved to EEPROM.");
    }
    else if (cmd.equalsIgnoreCase("p")) {
      Serial.println("\n--- Current Parameters ---");
      Serial.print("Lift: slope = "); Serial.print(slopeLift, 6); Serial.print(", intercept = "); Serial.println(interceptLift, 6);
      Serial.print("Drag: slope = "); Serial.print(slopeDrag, 6); Serial.print(", intercept = "); Serial.println(interceptDrag, 6);
      Serial.print("Pitot zero-voltage = "); Serial.print(offsetVoltage, 4); Serial.println(" V");
    }
    else if (cmd.length() > 0) {
      Serial.println("Unknown command. Use t, cl, cd, s, p.");
    }

    // Discard any half-filled window (commands can block for a while)
    resetAccumulators();
    printHeader();
  }

  // ---- Continuous measurement output ----
  if (calibrated && slopeLift != 0 && slopeDrag != 0) {
    streamMeasurements();
  } else {
    static unsigned long lastMsg = 0;
    if (millis() - lastMsg > 3000) {
      Serial.println("Missing calibration on one or both sensors. Type 'cl' or 'cd'.");
      lastMsg = millis();
    }
  }
}

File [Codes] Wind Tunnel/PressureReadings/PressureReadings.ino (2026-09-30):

const int sensorPin = A3;
const float V_REF = 4.93;          // Your exact measured voltage rail
const float air_density = 1.164;   // kg/m^3 for 30°C air

float offsetVoltage = 0.0;
float actualSensitivity = 1.0 * (V_REF / 5.0);

// Reference Pitot voltage after measuring U_inf
float pitotVoltage = 0.0;

void setup() {
  Serial.begin(9600);
  while (!Serial) { ; }

  Serial.println("STEP 1: Fan OFF. Calibrating zero-pressure baseline...");
  delay(2000);

  // MANDATORY TARE
  long sum = 0;
  for (int i = 0; i < 100; i++) {
    sum += analogRead(sensorPin);
    delay(10);
  }

  float avgADC = sum / 100.0;
  offsetVoltage = (avgADC * V_REF) / 1023.0;

  Serial.print("Baseline Zero-Voltage: ");
  Serial.print(offsetVoltage, 4);
  Serial.println(" V");

  Serial.println("-------------------------------------");

  Serial.println("STEP 2: Turn the fan ON and let the wind stabilize.");
  Serial.println("Type ANY character and press Enter to start measuring...");

  while (Serial.available() == 0) { }

  delay(50);
  while (Serial.available() > 0) {
    Serial.read();
  }

  Serial.println("-------------------------------------");

  // -------------------------------------------------
  // REFERENCE PITOT MEASUREMENT
  // -------------------------------------------------

  Serial.println("Measuring reference Pitot pressure...");

  sum = 0;
  for (int i = 0; i < 50; i++) {
    sum += analogRead(sensorPin);
    delay(5);
  }

  avgADC = sum / 50.0;
  pitotVoltage = (avgADC * V_REF) / 1023.0;

  float pitotDeltaV = pitotVoltage - offsetVoltage;

  // Convert Pitot voltage difference to pressure
  float pitotDeltaP_kPa = pitotDeltaV / actualSensitivity;
  float pitotPressure_Pa = fabs(pitotDeltaP_kPa * 1000.0);

  // Dynamic pressure q_inf
  float q_inf = pitotPressure_Pa;

  // Reference velocity
  float U_inf = 0.0;

  if (q_inf > 0.5) {
    U_inf = sqrt((2.0 * q_inf) / air_density);
  }

  Serial.print("Pitot Voltage: ");
  Serial.print(pitotVoltage, 4);
  Serial.println(" V");

  Serial.print("Reference Dynamic Pressure: ");
  Serial.print(q_inf, 1);
  Serial.println(" Pa");

  Serial.print("Reference Velocity U_inf: ");
  Serial.print(U_inf, 2);
  Serial.println(" m/s");

  Serial.println("-------------------------------------");
  Serial.println("Measuring live pressure and Cp...");
}

void loop() {

  // 1. Read sensor
  long sum = 0;

  for (int i = 0; i < 20; i++) {
    sum += analogRead(sensorPin);
    delay(5);
  }

  float avgADC = sum / 20.0;

  // 2. Convert ADC to voltage
  float V_out = (avgADC * V_REF) / 1023.0;

  // Voltage difference from zero-pressure baseline
  float deltaV = V_out - offsetVoltage;

  // 3. Convert voltage to pressure
  float deltaP_kPa = deltaV / actualSensitivity;

  float pressure_Pa = deltaP_kPa * 1000.0;          // signed tap pressure vs. reference port
  float abs_pressure_Pa = fabs(deltaP_kPa * 1000.0);

  // 4. Calculate velocity from absolute pressure
  float velocity = 0.0;

  if (abs_pressure_Pa > 0.5) {
    velocity = sqrt((2.0 * abs_pressure_Pa) / air_density);
  }

  // -------------------------------------------------
  // 5. DIRECT VOLTAGE-RATIO Cp
  // -------------------------------------------------

  float Cp = 0.0;

  float pitotDeltaV = pitotVoltage - offsetVoltage;

  if (fabs(pitotDeltaV) > 0.001) {
    Cp = deltaV / pitotDeltaV;
  }

  // -------------------------------------------------
  // 6. Local velocity ratio from Cp
  // -------------------------------------------------

  float velocityRatio = (Cp < 1.0) ? sqrt(1.0 - Cp) : 0.0;   // avoid NaN when Cp >= 1

  // -------------------------------------------------
  // 7. Output
  // -------------------------------------------------

  Serial.print("Voltage: ");
  Serial.print(V_out, 4);
  Serial.print(" V  |  ");

  Serial.print("Pressure: ");
  Serial.print(pressure_Pa, 1);
  Serial.print(" Pa  |  ");

  Serial.print("Velocity: ");
  Serial.print(velocity, 2);
  Serial.print(" m/s  |  ");

  Serial.print("Cp (V-ratio): ");
  Serial.print(Cp, 4);
  Serial.print("  |  ");

  Serial.print("U/U_inf: ");
  Serial.print(velocityRatio, 3);

  Serial.println();

  delay(250);
}

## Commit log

2026-09-30 Initial upload: firmware, MATLAB, CAD, CFD setup and results
    [(Obsolete) Ahmed body.SLDPRT, (obsolete) NACA 0012 model.SLDPRT, Ahmed Assembly.SLDASM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]
2026-09-30 File Structure Changed
    [CFD_Results.xlsx, Wind_Tunnel_Experimental_Coefficients.xlsx, ahmed_cfd_stats.csv]
2026-09-30 Minor fixes
    [Square Flanges for Settling Chamber and Diffuser.DXF, Square Flanges for Settling Chamber and Diffuser.SLDPRT]
2026-10-01 added report and poster
    [Contraction cone.SLDPRT, Load Cell.SLDPRT, NACA 4418 model.SLDPRT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]
2026-10-01 readme fix
    [Wind Tunnel w NACA 4418.SLDASM]
2026-10-02 Final Changes
    [(obsolete) NACA 0012 model_.SLDPRT, NACA 4418 model.SLDPRT]
2026-10-02 CAD Changes
    [(Obsolete) Ahmed body.SLDPRT, NACA 4418 model.SLDPRT]
